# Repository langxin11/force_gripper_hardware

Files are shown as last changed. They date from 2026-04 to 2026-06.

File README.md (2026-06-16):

# Learning Force-Regulated Manipulation with a Low-Cost Tactile-Force-Controlled Gripper



Force Gripper Overview

## Overview

This repository contains the hardware design and assembly guide for our **low-cost tactile-force-controlled gripper**, designed for studying force-regulated manipulation in robot learning. The gripper features:

## Hardware Documentation

This repository provides complete hardware implementation guides:

- **[Bill of Materials (BOM)](BOM.md)** - Complete list of components with prices and suppliers
- **[3D Printing Guide](3D_printing_guide.md)** - Instructions for printing custom parts
- **[Assembly Guide](Assembly_guide.md)** - Step-by-step assembly instructions
- **Tactile sensor** - See [FlexiTac](https://flexitac.github.io)
- **[Code Setup and Usage Guide](code.md)** - Arduino IDE configuration, motor setup, and firmware uploading
- **[Code Architecture Reference](code/README.md)** - Code directory structure, data flow, and parameter quick reference

## Support

Building such a gripper may involve different errors depending on your environment. If you encounter any issues, please feel free to **create an issue** in this repository or send an email to **xuhui@virginia.edu**. I will respond as soon as possible.

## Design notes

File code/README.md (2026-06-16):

# Code — 力控夹爪软件代码

本目录包含下位机固件（OpenRB-150 Arduino 程序）和上位机 ROS 包（Python），实现夹爪的遥操作力控。

---

## 目录结构

```
code/
├── README.md                                   # ← 你正在看的文件
├── openrb150/                                  # 下位机固件（Arduino）
│   ├── control_gripper_width_force/            # 主控：双电机位置/力控
│   ├── teleoperator/                           # 遥操作：读取负载传感器
│   ├── scan_ids/                               # 工具：扫描总线上的舵机 ID
│   ├── update_motor_id/                        # 工具：修改舵机 ID
│   ├── modify_motor_bitrate/                   # 工具：修改舵机波特率
│   └── test_single_motor_control/              # 测试：单电机控制
└── force_control_gripper/                      # 上位机（ROS Python 包）
    ├── force_gripper/                          # 核心模块
    │   ├── gripper/gripper_ros.py              # 夹爪驱动 ROS 节点
    │   ├── teleoperator/teleoperation_ros.py   # 遥操作映射 ROS 节点
    │   ├── tactile/tactile_ros.py              # 触觉传感器 ROS 节点
    │   ├── utils/load_device.py                # 串口设备查找工具
    │   └── config/devices.yaml                 # 设备配置文件
    └── scripts/                                # 独立测试/调试脚本
```

---

## 整体架构

```
 ┌──────────────────────┐      ┌─────────────────────────┐      ┌──────────────────────┐
 │  遥操作手柄 (Arduino) │      │  PC (ROS Noetic)        │      │  OpenRB-150 主控     │
 │                      │      │                         │      │                      │
 │  电机3 & 电机4       │──串口──│  teleoperation_ros.py  │──ROS──│  gripper_ros.py      │──串口──│  control_gripper_    │
 │  (负载传感)          │      │  读取 L3:val,L4:val     │ topic│  构造 JSON 指令      │        │  width_force.ino     │
 │                      │      │  映射为 PWM/Open 指令   │      │  收发 <"cmd",...>    │        │                      │
 └──────────────────────┘      └─────────────────────────┘      └──────────────────────┘
                                                                          │
                               ┌─────────────────────────┐      驱动 PWM  │  电机1 (开合)
                               │  tactile_ros.py         │          ┌─────┴─────┐
                               │  读取左右触觉传感器      │          │  电机2 (开合)
                               │  发布压力图像            │          └───────────┘
                               │  /tactile_left/image_raw │
                               │  /tactile_right/image_raw│
                               └─────────────────────────┘
```

---

## openrb150/ — 下位机固件详解

### `control_gripper_width_force/control_gripper_width_force.ino`（主控程序）

**功能**：驱动夹爪两个 Dynamixel 电机（ID 1 & 2），运行在 PWM 模式：
- 上电自动执行**机械限位标定**（分别找开极限和闭极限）
- **50Hz 主循环**：读取位置 → 计算控制量 → 输出 PWM → 回传状态
- 支持两种控制模式：
  - **位置模式 (MODE_POS)**：上位机下发归一化目标位置 `[0,1]` + 前馈 PWM，板载 P 控制器转换为 PWM
  - **PWM 模式 (MODE_PWM)**：上位机直接下发归一化 PWM `[-1,1]`，直驱电机

**串口**：
| 端口 | 用途 | 波特率 |
|---|---|---|
| `Serial` (USB) | 接收指令 | 1,000,000 |
| `Serial3` (USB2TTL) | 回传状态 | 1,000,000 |

**指令格式**（以 `<"cmd", args>` 通过 USB 串口发送）：
| 指令 | 示例 | 说明 |
|---|---|---|
| `initialization` | `<"initialization">` | 重新执行限位标定 |
| `open` | `<"open">` | 回到全开位置（位置模式） |
| `pos` | `<"pos", 0.5, 0.3>` | 位置模式：目标归一化位置 |
| `motion` | `<"motion", 0.5, 0.1, 0.3, -0.05>` | 位置模式 + 前馈 PWM |
| `pwm` | `<"pwm", 0.2, -0.15>` | PWM 直驱模式：归一化 PWM |

**状态回传格式**（50Hz，Serial3）：
```
<1,pos_norm,tgt_norm,pwm_norm,2,pos_norm,tgt_norm,pwm_norm>
```

---

### `teleoperator/teleoperator.ino`

**功能**：读取遥操作手柄两个电机（ID 3 & 4）的负载值，以 100Hz 频率通过串口输出：
```
L3:50,L4:-20
```
波特率 115200。

---

### 工具固件

| 文件 | 用途 |
|---|---|
| `scan_ids/scan_ids.ino` | 遍历 5 种波特率、0~252 的 ID，ping 发现所有挂载的 Dynamixel 舵机 |
| `update_motor_id/update_motor_id.ino` | 将指定舵机 ID 改为新 ID（需先确保只有目标舵机在线） |
| `modify_motor_bitrate/modify_motor_bitrate.ino` | 将指定舵机波特率从 57600 改为 1000000（1Mbps） |
| `test_single_motor_control/test_single_motor_control.ino` | 单电机基础控制测试 |

---

## force_control_gripper/ — 上位机 ROS 包详解

### `gripper/gripper_ros.py` — 夹爪驱动节点

**节点名**：`gripper_controller`

- 订阅 `/gripper/command`（`std_msgs/String`），接收 JSON 指令
- 通过 `force_gripper.utils.find_port_by_name()` 自动查找串口：`"gripper"` → 指令口，`"gripper_usb2ttl"` → 状态口
- 发送 `<"cmd",...>` 给 Arduino，同时线程读取并解析状态
- 发布 `/gripper/state`（`sensor_msgs/Joy`）：buttons=[ID1, ID2]，axes=[pos, tgt, pwm × 2]

**JSON 指令格式**（通过 `/gripper/command` topic）：
```json
{"node": "gripper", "command": "pos", "value": [0.5, 0.3]}
{"node": "gripper", "command": "pwm", "value": [0.2, -0.1]}
{"node": "gripper", "command": "open"}
{"node": "gripper", "command": "init"}
```

---

### `teleoperator/teleoperation_ros.py` — 遥操作映射节点

**节点名**：`teleop_to_gripper_controller`

- 从 `"teleoperator"` 串口读取 `L3:val,L4:val`
- 归一化后（除以 885），根据负载极性决定夹爪动作：
  - **负载 > 0.02**（外推）→ 发送 `open` 指令（夹爪张开）
  - **负载 < 0**（内收）→ 发送 `pwm` 指令（夹爪闭合），可选平均两电机负载
  - **负载 ~0** → 停止（PWM=[0,0]）
- 发布 JSON 指令到 `/gripper/command`

---

### `tactile/tactile_ros.py` — 触觉传感器节点

**节点名**：`dual_tactile_node`

- 从左右两个触觉传感器串口读取 16×32 压力矩阵
- 背景减除 + 阈值 + 归一化处理
- 发布：
  - `/tactile_left/image_raw`（`sensor_msgs/Image`, 32FC1）
  - `/tactile_right/image_raw`
- 提供服务 `/tactile/reinit`（`std_srvs/Trigger`）用于重新标定基线

---

### `utils/load_device.py` — 串口查找工具

通过 USB 设备描述符关键字自动匹配串口路径，避免每次手动指定 `/dev/ttyUSB*`。

### `config/devices.yaml` — 设备配置

定义各设备的关键字映射。

---

### `scripts/` — 独立脚本

| 脚本 | 用途 |
|---|---|
| `control_gripper_single_file.py` | 最简用：单文件控制夹爪（不依赖 ROS） |
| `keyboard_control_ros.py` | 键盘遥控夹爪 |
| `check_serial_number.py` | 检查并列出系统串口设备 |
| `test_teleoperator_serial.py` | 测试遥操作串口数据读取 |

---

## 快速上手

### 1. 烧录固件
在 Arduino IDE 中分别将以下 `.ino` 文件烧录到两块 OpenRB-150 控制板：
- **主控板**：`openrb150/control_gripper_width_force/`
- **遥操作板**：`openrb150/teleoperator/`

### 2. 安装上位机包
```bash
cd code/force_control_gripper
pip install -e .
```

### 3. 运行
```bash
# 终端 1：夹爪驱动
rosrun force_gripper gripper_ros.py

# 终端 2：遥操作映射
rosrun force_gripper teleoperation_ros.py

# （可选）终端 3：触觉传感器
rosrun force_gripper tactile_ros.py
```

### 4. 调试工具
- 扫描舵机：烧录 `scan_ids.ino`，查看串口监视器
- 修改 ID：烧录 `update_motor_id.ino`
- 修改波特率：烧录 `modify_motor_bitrate.ino`

---

## 关键参数速查

| 参数 | 值 | 位置 |
|---|----|---|
| 主控控制频率 | 50 Hz | `control_gripper_width_force.ino` |
| DXL 舵机波特率 | 1,000,000 bps | 同上 |
| PWM 范围 | [-885, 885] | 同上 |
| 位置控制器 KP | 0.6 | 同上 |
| 遥操作串口波特率 | 115,200 bps | `teleoperator.ino` |
| 遥操作负载归一化因子 | 885.0 | `teleoperation_ros.py` |
| 触觉传感器阵列 | 16 × 32 | `tactile_ros.py` |
| 触觉传感器波特率 | 2,000,000 bps | `tactile_ros.py` |

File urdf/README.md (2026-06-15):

# Force Control Gripper URDF

A two-finger parallel gripper in URDF, with two PyBullet keyboard demos.

This URDF was generated directly by Autodesk Fusion (URDF export); the collision
geometry is the raw exported mesh and has not been optimized. If you have
suggestions for improving it, feel free to reach out: **xuhui@virginia.edu**

## The two demos

- `keyboard_control.py` — both fingers move **together** symmetrically (a single open/close value), like a normal parallel gripper.
- `keyboard_control_independent.py` — each fingertip is controlled **independently** and can travel the full span (one can move all the way across to the other side); they collide with each other instead of passing through.

## Run

```bash
conda install -c conda-forge pybullet   # or: pip install pybullet
python keyboard_control.py
python keyboard_control_independent.py
```

Each script opens a PyBullet GUI; control the gripper with the keyboard (the on-screen prints list the keys, e.g. `O`/`C` to open/close, `Q` to quit).

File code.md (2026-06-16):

- [1. Gripper Setup](#1-gripper-setup)
- [2. Teleoperator Setup](#2-teleoperator-setup)

## Prerequisites

This guide assumes you're using the OpenRB-150 board with Arduino. If you're new to Arduino, we recommend learning the basics first. Configure your Arduino IDE according to the official documentation: [OpenRB-150 Arduino IDE Setup](https://emanual.robotis.com/docs/en/parts/controller/openrb-150/#install-the-arduino-ide).

> 📖 For a technical overview of the code architecture, data flow, and parameter reference, see **[code/README.md](code/README.md)**.

# 1. Gripper Setup

## 1.1 Motor Detection and Setup

Use `code/openrb150/scan_ids` to verify successful connection and detect motors. Motors ship with ID 1 by default. In this example, one motor has been set to ID 2.

Note that 57600 is the baud rate for OpenRB-150 to motor communication, not PC to OpenRB-150. Default is 57600, but we'll upgrade to 2000000 later for better performance.

Expected output when motors are detected:
```
SCAN PROTOCOL 2
SCAN BAUDRATE 57600
ID : 1, Model Number: 1060
ID : 2, Model Number: 1060
SCAN BAUDRATE 115200
SCAN BAUDRATE 1000000
SCAN BAUDRATE 2000000
SCAN BAUDRATE 3000000
Total 2 DYNAMIXEL(s) found!
```

## 1.2 Motor ID Configuration

Motors ship with ID 1 by default. We'll change one to ID 2. Connect only one motor at a time, as the code detects ID 1 and changes it to 2.

Use: `code/openrb150/update_motor_id/update_motor_id.ino`

Set the source and target IDs:
```cpp
const uint8_t source_id = 1;
const uint8_t new_id = 2;
```

Expected output:
```
PROTOCOL 2.0, ID 1: ping succeeded!, Model Number: 1060
ID has been successfully changed to 2
```

## 1.3 Single Motor PWM Test

Load test code to verify PWM control of individual motors.

Use: `code/openrb150/test_single_motor_control/test_single_motor_control.ino`

Configure the target motor ID:
```cpp
const uint8_t DXL_ID = 2;    // Specify Motor ID here
```

After uploading, use Arduino IDE Serial Monitor to test PWM values. Enter values like 200 or -200 (range: -885 to +885) to see forward/reverse rotation.

Serial Test

## 1.4 Main Gripper Control Code

Once testing is successful, upload the main gripper control code.

Use: `code/openrb150/control_gripper_width_force/control_gripper_width_force.ino`

Configure baud rates and other settings at the top of the file. OpenRB-150 to motor communication defaults to 57600. See step 5 for upgrading to 1000000.

After uploading, you'll need a Python script for control and feedback. This guide uses ROS 1. ROS-independent versions may be available later.

## Serial Port Configuration

Serial ports vary by operating system, so we identify them by serial number.

If you purchased a USB2TTL adapter for real-time gripper state feedback, see [Section 1.6: Real-Time Gripper State via USB2TTL](#16-real-time-gripper-state-via-usb2ttl).

1. Run `code/force_control_gripper/scripts/check_serial_number.py` to identify device information
2. Update `code/force_control_gripper/force_gripper/config/devices.yaml` with gripper device info for automatic detection

## Installation

### Package Installation

Navigate to the package directory and install in development mode:

```bash
cd code/force_control_gripper
pip install -e .
```

This will install the `force_gripper` package with its dependencies, allowing you to use the utility functions for serial port detection.

## ROS-Based Control

Run `python code/force_control_gripper/force_gripper/gripper/gripper_ros.py` (requires ROS core to be running).

This establishes communication with the gripper.

## ROS-Independent Interactive Control

For ROS-free operation, use the interactive control script: `code/force_control_gripper/scripts/control_gripper_single_file.py`

Launch the script:
```bash
python code/force_control_gripper/scripts/control_gripper_single_file.py
```

Then enter commands at the `gripper>` prompt:

```
gripper> init          # Initialize
gripper> open          # Fully open
gripper> pos 0.5 0.5   # Set position (0.0-1.0)
gripper> pwm 0.3 -0.3  # PWM control (-1.0 to 1.0)
gripper> state         # Show current status
gripper> help          # Show help
gripper> quit          # Exit
```

If a status serial port (USB2TTL, such as CH340 or CP2102) is available, real-time status will be displayed. Otherwise, status shows as null. If you purchased a USB2TTL adapter, see [Section 1.6: Real-Time Gripper State via USB2TTL](#16-real-time-gripper-state-via-usb2ttl).

## 1.5 Optional: Motor Baud Rate Optimization

Improve communication speed by modifying motor baud rates.

Use: `code/openrb150/modify_motor_bitrate/modify_motor_bitrate.ino`

Configure motor ID and target baud rate at the top of the file. Default is 57600. Testing shows 1000000 provides significant speed improvements.

## 1.6 Real-Time Gripper State via USB2TTL

To read the gripper state in real time, we separate the command serial port from the status serial port.

If you use a USB2TTL adapter such as a CH340 or CP2102, connect it as shown below:

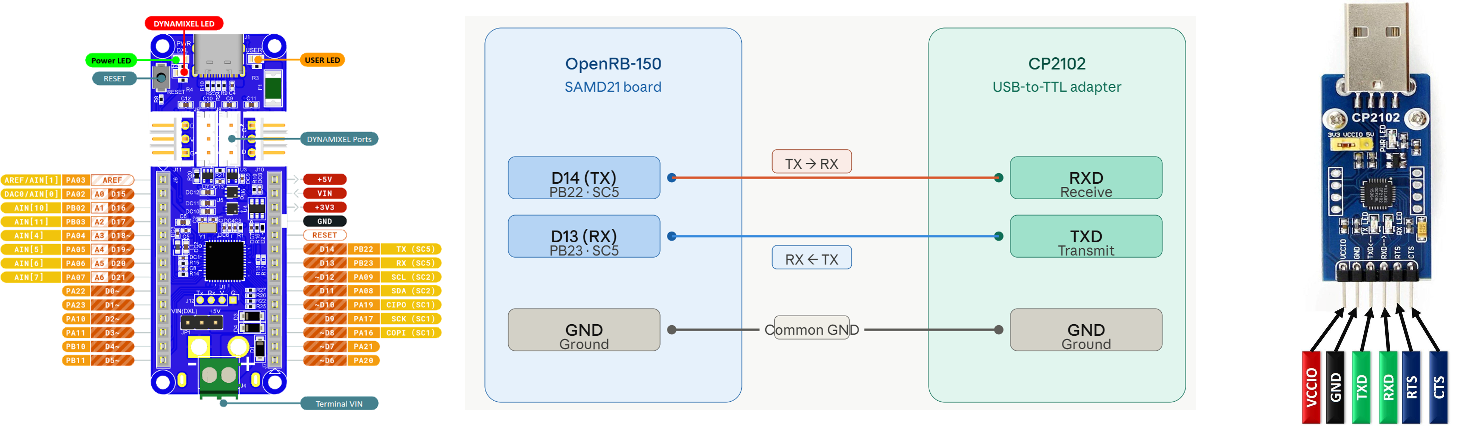
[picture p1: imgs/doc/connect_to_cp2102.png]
USB2TTL wiring for real-time gripper state


Once connected, this serial port will continuously return the gripper state.

## 1.7 Optional: Tactile ROS Publishing

The tactile sensors and the gripper are controlled separately.

If you have built the tactile sensors, you can run `code/force_control_gripper/force_gripper/tactile/tactile_ros.py` to continuously publish tactile information.

```bash
python code/force_control_gripper/force_gripper/tactile/tactile_ros.py
```

This node reads the left and right tactile serial ports independently and continuously publishes tactile data to ROS topics.
# 2. Teleoperator Setup

The teleoperator system uses a separate OpenRB-150 board to read load (force) feedback from two Dynamixel motors (we use IDs 3 and 4). 

## 2.1 Hardware Preparation
1. Connect two Dynamixel motors to the OpenRB-150.
2. Ensure the motors have IDs 3 and 4 (use the `scan_ids` and `update_motor_id` tools if necessary).

## 2.2 Arduino Code Deployment
Use: `code/openrb150/teleoperator/teleoperator.ino`

- **Baud Rate**: The motor communication is set to 57600. The PC serial communication is set to 115200.
- **Output Format**: The board sends data in the format `L3:value,L4:value\n` at approximately 100Hz.

## 2.3 Configuration
Identify the teleoperator's serial number and add it to `code/force_control_gripper/force_gripper/config/devices.yaml`:

```yaml
devices:
  teleoperator:
    serial: "YOUR_SERIAL_NUMBER"
    vid: 33261
    pid: 144
```

## 2.4 Testing the Connection
You can use the dedicated test script to verify that the PC is receiving data correctly:

```bash
python code/force_control_gripper/scripts/test_teleoperator_serial.py
```

The script will automatically find the port, send a wake-up character, and start printing the force/load data from IDs 3 and 4.

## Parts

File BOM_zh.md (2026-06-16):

# force_gripper_hardware

## 物料清单（BOM）

| 名称 | 链接 | 单价 | 所需数量 | 总价 | 备注 |
|---|---|---|---|---|---|
| XL430W250T | [Robotis](https://www.robotis.us/dynamixel-xl430-w250-t/) | $27.50 | 2 | $55.00 | Dynamixel 舵机电机，另需使用随附的 4 颗 M2.5 x 14 螺丝 |
| OpenRB-150 | [Robotis](https://www.robotis.us/openrb-150/) | $28.64 | 1 | $28.64 | 控制板。也可以使用 Dynamixel 官方 U2D2 控制套件，但价格更高 |
| MGN12H Linear Guide Rail 200MM with 2 Blocks | [Amazon](https://www.amazon.com/gp/product/B0C3VGRP6Q/ref=ox_sc_act_title_1?smid=A1YHW98JPGEZ14&th=1) | $24.98 | 1 | $24.98 | 线性导轨和滑块 |
| HTD3M Timing Belt | [Amazon](https://www.amazon.com/gp/product/B09KKXY8YS/ref=ox_sc_act_title_5?smid=A1W08XZBT3V7EI&psc=1) | $11.99 | 1 m | $5.99 | 同步带，需要 1 米 |
| Filament 1kg | [Amazon](https://www.amazon.com/Official-Creality-Precision-Toughness-Moistureproof/dp/B0C8NP63GD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) | $19.99 | 400 g | $7.99 | 每个夹爪约需 400 g，任意品牌均可，PLA、PETG、ABS 理论上都可以使用 |
| TPU 95 Filament 0.75kg | [Amazon](https://www.amazon.com/dp/B09KKZLZVR/ref=twister_B0F3Y1MWFK?_encoding=UTF8&th=1) | $23.99 | 150 g | $4.80 | 约需 150 g，任意品牌均可 |
| Flange Bearing F685-2RS 5x11x5mm | [Amazon](https://www.amazon.com/gp/product/B0D7BYFGVT/ref=ox_sc_act_title_3?smid=A1THAZDOWP300U&th=1) | $13.09 | 2 | $2.62 | 一包 10 个轴承，只需要 2 个 |
| Steel Dowel Pin | [Amazon](https://www.amazon.com/gp/product/B0F5W619BC/ref=ox_sc_act_title_4?smid=A3SSR6IRE5S2JM&psc=1) | $9.99 | 2 | $2.00 | 一包 10 个，只需要 2 个，长度 35 mm |
| AC Adapter 12V 4A | [Amazon](https://www.amazon.com/COOLM-100-240V-Adapter-5-5x2-5mm-5-5x2-1mm/dp/B07H493GHX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) | $11.90 | 1 | $11.90 | 需要 12 V 且大于 3 A，包含接头 |
| Dupont Wire Kit | [Amazon](https://www.amazon.com/Elegoo-EL-CP-004-Multicolored-Breadboard-arduino/dp/B01EV70C78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) | $6.98 | 约 1/3 包 | $2.33 | 用于连接 OpenRB-150 和电机。需要：5 根公对公、3 根母对母 |
| M3 Screw Set | [Amazon](https://www.amazon.com/Kadrick-Assortment-M3x4MM-35MM-Machine-Anti-Rust/dp/B0BRWCFD6Q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) | $19.99 | 约 1/5 包 | $4.00 | 需要：M3 10 mm x 2、M3 35 mm x 6、M3 20 mm x 2、M3 螺母 x 10、M3 8 mm x 8 |
| M6 Screws 12mm with Nuts | [Amazon](https://www.amazon.com/Screws-Assortment-Stainless-Socket-Washers/dp/B0DFWMGFDM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) | $8.99 | 2 | $2.25 | 用于将夹爪安装到 Franka 上（ISO 9409-1-A50）。包装内含 8 颗 M6 x 12 mm 螺丝，只需要 2 颗。也兼容 UR5、xArm 等 |
| M2 Screws 5mm | [Amazon](https://www.amazon.com/Socket-Stainless-Threaded-Furniture-Printing/dp/B0DKY77B3B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) | $6.59 | 8 | $0.88 | 一包 60 颗，需要 8 颗 |
| USB2TTL Serial Module（可选） | [Amazon](https://www.amazon.com/HiLetgo-Module-Microcontroller-Download-Serial/dp/B00LZV1G6K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) | $9.79 | 1 | $1.96 | 用于状态通道的 USB2TTL 适配器，例如 CH340 或 CP2102。对于电机控制和反馈使用独立发送/接收通道的学习场景，这是可选项。一包 5 个，只需要 1 个 |

**总成本：$152.34**

说明：

1. 除电机和 OpenRB-150 之外，其他零件都是标准件，可以购买任意品牌的等效型号。
2. 除 HTD3M 同步带外，我们也测试过 GT2 和 HTD5M。测试发现 GT2 太薄太软，在大力夹持时容易跳齿；HTD5M 则太硬，张紧需要较大力。
3. 使用电机随附的螺丝将电机安装到底座上。
4. 除了需要采购的物料外，还需要螺丝刀套装、剪刀、胶带和 3D 打印机等工具。由于 3D 打印孔位可能不是完全圆形，有时可以用锤子将钢制定位销轻轻敲入。
5. 状态反馈模块可以使用任意 USB2TTL 适配器，例如 CH340 或 CP2102。CH340 模块通常不会暴露序列号，因此多块 CH340 模块同时连接时可能难以区分。如果机器上连接了多个 USB2TTL 适配器，CP2102 或其他带可读序列号的芯片通常更容易管理。

## 遥操作器

如果需要制作一个不带 VR 的遥操作器，只需要：

- 2 x XL430W250T 电机
- 1 x OpenRB-150 控制器
- 1 x 12 V 4 A 交流电源适配器
- 杜邦线

**估算成本：$97.87**

实际使用中我们发现 VR 头显可能比较重。如果感觉太重，建议一只手握持遥操作器，另一只手握持 VR 头显。

## 触觉传感器

触觉传感器制作请参考 [FlexiTac](https://flexitac.github.io/)。

# 参考与致谢

1. [MAGPIE](https://github.com/correlllab/MAGPIE)
2. [UMI](https://umi-gripper.github.io)
3. [FlexiTac](https://flexitac.github.io/)

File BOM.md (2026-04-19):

# force_gripper_hardware

## Bill of Materials (BOM)

| Name | Link | Unit Price | Quantity Needed | Total Price | Notes |
|---|---|---|---|---|---|
| XL430W250T | [Robotis](https://www.robotis.us/dynamixel-xl430-w250-t/) | $27.50 | 2 | $55.00 | Dynamixel servo motor (also need 4 included M2.5×14 screws) |
| OpenRB-150 | [Robotis](https://www.robotis.us/openrb-150/) | $28.64 | 1 | $28.64 | Controller board (can also use Dynamixel's official U2D2 control set, but more expensive) |
| MGN12H Linear Guide Rail 200MM with 2 Blocks | [Amazon](https://www.amazon.com/gp/product/B0C3VGRP6Q/ref=ox_sc_act_title_1?smid=A1YHW98JPGEZ14&th=1) | $24.98 | 1 | $24.98 | Linear rail and carriage blocks |
| HTD3M Timing Belt | [Amazon](https://www.amazon.com/gp/product/B09KKXY8YS/ref=ox_sc_act_title_5?smid=A1W08XZBT3V7EI&psc=1) | $11.99 | 1m | $5.99 | Timing belt (1 meter needed) |
| Filament 1kg | [Amazon](https://www.amazon.com/Official-Creality-Precision-Toughness-Moistureproof/dp/B0C8NP63GD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) | $19.99 | 400g | $7.99 | ~400g needed per gripper, any brand works (PLA, PETG, ABS should all work) |
| TPU 95 Filament 0.75kg | [Amazon](https://www.amazon.com/dp/B09KKZLZVR/ref=twister_B0F3Y1MWFK?_encoding=UTF8&th=1) | $23.99 | 150g | $4.80 | ~150g needed, any brand works |
| Flange Bearing F685-2RS 5x11x5mm | [Amazon](https://www.amazon.com/gp/product/B0D7BYFGVT/ref=ox_sc_act_title_3?smid=A1THAZDOWP300U&th=1) | $13.09 | 2 | $2.62 | Pack of 10 bearings, only 2 needed |
| Steel Dowel Pin | [Amazon](https://www.amazon.com/gp/product/B0F5W619BC/ref=ox_sc_act_title_4?smid=A3SSR6IRE5S2JM&psc=1) | $9.99 | 2 | $2.00 | Pack of 10, only 2 needed (35mm) |
| AC Adapter 12V 4A | [Amazon](https://www.amazon.com/COOLM-100-240V-Adapter-5-5x2-5mm-5-5x2-1mm/dp/B07H493GHX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) | $11.90 | 1 | $11.90 | 12V >3A required, includes connector |
| Dupont Wire Kit | [Amazon](https://www.amazon.com/Elegoo-EL-CP-004-Multicolored-Breadboard-arduino/dp/B01EV70C78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) | $6.98 | ~1/3 | $2.33 | For connecting OpenRB-150 and motors. Need: 5 male-to-male, 3 female-to-female |
| M3 Screw Set | [Amazon](https://www.amazon.com/Kadrick-Assortment-M3x4MM-35MM-Machine-Anti-Rust/dp/B0BRWCFD6Q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) | $19.99 | ~1/5 | $4.00 | Need: M3 10mm ×2, M3 35mm ×6, M3 20mm ×2, M3 nuts ×10, M3 8mm ×8 |
| M6 Screws 12mm with Nuts | [Amazon](https://www.amazon.com/Screws-Assortment-Stainless-Socket-Washers/dp/B0DFWMGFDM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) | $8.99 | 2 | $2.25 | For mounting gripper to Franka (ISO 9409-1-A50). Pack contains 8 M6×12mm screws, only 2 needed. Compatible with UR5, xArm, etc. |
| M2 Screws 5mm | [Amazon](https://www.amazon.com/Socket-Stainless-Threaded-Furniture-Printing/dp/B0DKY77B3B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) | $6.59 | 8 | $0.88 | Pack of 60, 8 needed |
| USB2TTL Serial Module (Optional) | [Amazon](https://www.amazon.com/HiLetgo-Module-Microcontroller-Download-Serial/dp/B00LZV1G6K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) | $9.79 | 1 | $1.96 | USB2TTL adapter for the status channel, such as CH340 or CP2102. Optional for learning scenarios with separate send/receive channels for motor control and feedback. Pack of 5, 1 needed. |

**Total Cost: $152.34**

Notes:
1. Except for the motors and OpenRB-150, all other components are standard parts. You can purchase equivalent models from any brand.
2. Besides HTD3M timing belt, we also tested GT2 and HTD5M. We found that GT2 is too thin and soft, prone to tooth skipping under high force, while HTD5M is too stiff and requires significant force to tension.
3. Use the included screws from the motors to mount them to the base.
4. Besides the items to purchase, you will need some tools including a screwdriver set, scissors, tape, and a 3D printer. Since 3D printed holes may not be perfectly round, you can sometimes use a hammer to tap in the Steel Dowel Pins.
5. The status feedback module can be any USB2TTL adapter, such as CH340 or CP2102. CH340 modules often do not expose a serial number, so different CH340 modules may be hard to distinguish. If your machine connects to multiple USB2TTL adapters, CP2102 or another chip with a readable serial number is usually easier to manage.
## Teleoperator

If you need to build a teleoperator (without VR), you only need:

- 2 × XL430W250T motors
- 1 × OpenRB-150 controller
- 1 × AC Adapter 12V 4A
- Dupont wires

**Approximate cost: $97.87**

During actual use, we found that VR headsets can be quite heavy, so if it feels too heavy, we recommend holding the teleoperator in one hand and the VR headset in the other hand.

## Tactile Sensor
For tactile sensor fabrication, please refer to [FlexiTac](https://flexitac.github.io/).

# References and Acknowledgments
1. [MAGPIE](https://github.com/correlllab/MAGPIE)
2. [UMI](https://umi-gripper.github.io)
3. [FlexiTac](https://flexitac.github.io/)

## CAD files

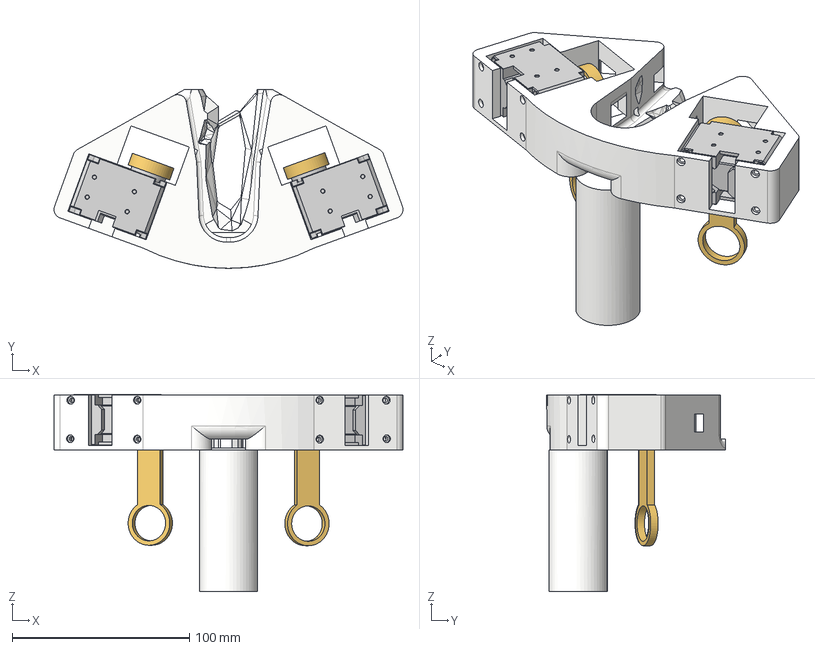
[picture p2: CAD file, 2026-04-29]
cad/teleoperator.step
197.0 x 100.8 x 111.2 mm
DC11_A01_DUMMY
human_figure x 2
DC11_A01_DUMMY_1
DX124_SCREW-COVER_1
B3B-EH_1 x 2
DC11_A01_CASE_CVR_DUMMY_1
DC11_A01_IDLER_DUMMY_1
DC11_A01_IDLER_CAP_DUMMY_1
DC11_A01_IDLER_SCREW_1
FHS_M2_5X10_1 x 8
DC11_A01_SPACER_DUMMY_1 x 8

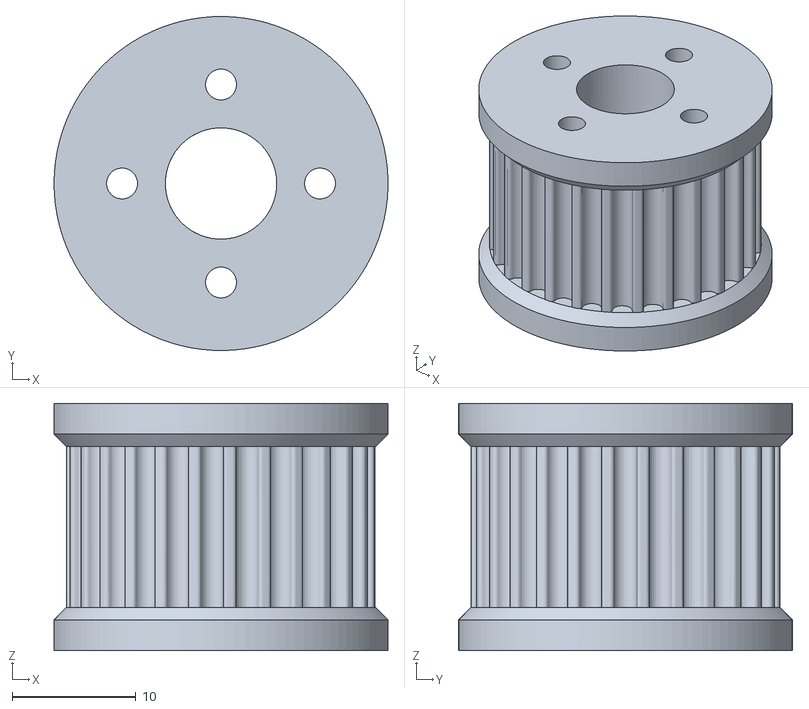
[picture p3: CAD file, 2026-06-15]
print_parts/driving_pulley.stl
27.0 x 27.0 x 20.0

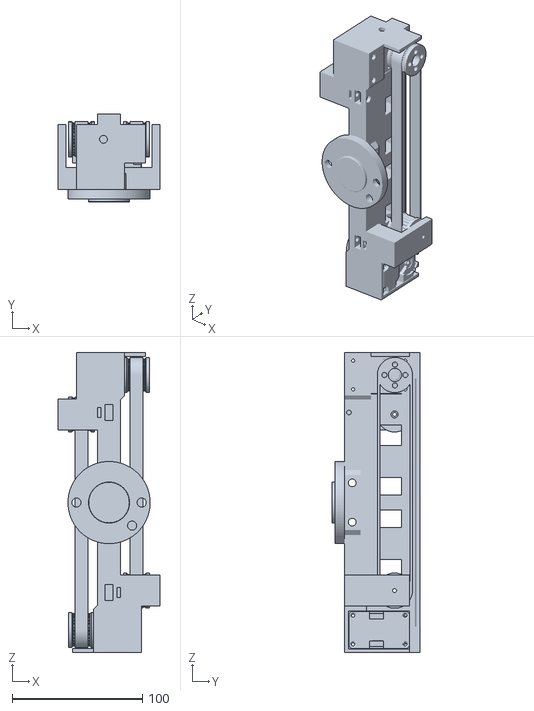
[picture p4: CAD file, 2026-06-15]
urdf/meshes/base-1.stl
78.0 x 67.5 x 230.0

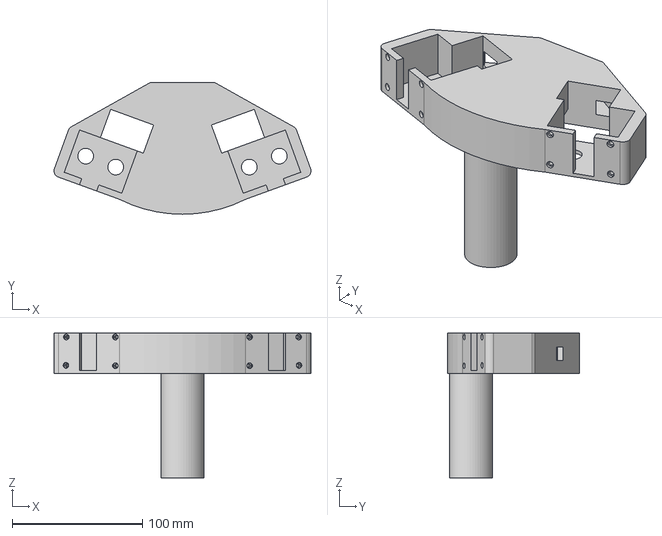
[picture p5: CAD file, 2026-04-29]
cad/teleoperator_solid.step
197.0 x 100.8 x 111.0 mm

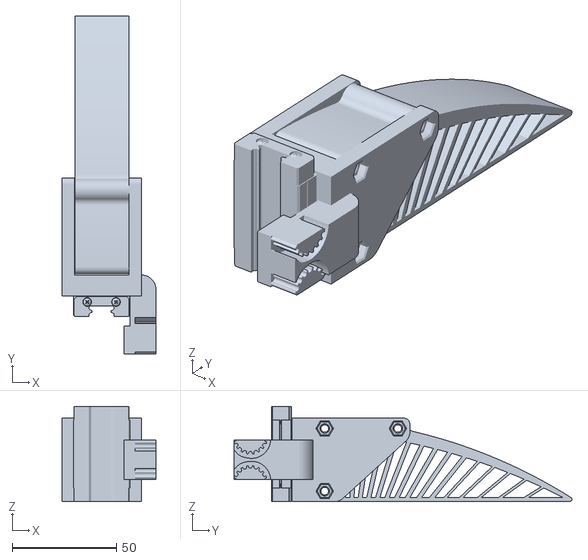
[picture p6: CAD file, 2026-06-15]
urdf/meshes/right_figure.stl
45.0 x 161.9 x 45.6

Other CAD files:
urdf/meshes/left_figure.stl

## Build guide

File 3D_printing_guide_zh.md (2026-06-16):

# 3D 打印指南

3D 打印机没有品牌限制，只要能打印 TPU/PLA/PETG 即可。大多数主流打印机都可以使用。作者本人使用的是 BambuLab P1S 和 Creality Ender V2。

只有指尖部分需要使用 TPU 打印。其他所有零件都可以使用 PLA、PETG、ABS 等刚性材料。

需要打印的零件：

1. **框架** - [holder_base.stl](./print_parts/holder_base.stl)
   - 推荐填充率大于 45%，以保证强度。使用 100% 填充也可以。
   - 框架

2. **指尖固定座** x 2 - [gripper_figure_tip_holder.stl](./print_parts/gripper_figure_tip_holder.stl)
   - 推荐填充率 100%。
   - 指尖固定座

3. **从动同步轮** x 2 - [idler_pulley.stl](./print_parts/idler_pulley.stl)
   - 推荐填充率 100%。
   - 从动同步轮

4. **主动同步轮** x 2 - [driving_pulley.stl](./print_parts/driving_pulley.stl)
   - 推荐填充率 100%。
   - 主动同步轮

5. **UMI 指尖** x 2 - [UMI_figure_tip.stl](./print_parts/UMI_figure_tip.stl)
   - 使用 TPU 打印，填充率 100%。建议一次只打印一个，不要两个一起打印，因为 TPU 容易拉丝。
   - UMI 指尖

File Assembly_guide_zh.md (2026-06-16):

# 装配指南

装配过程比较直接，大约需要 15 分钟。所需采购零件请参考 [BOM_zh.md](BOM_zh.md)，3D 打印零件请参考 [3D_printing_guide_zh.md](3D_printing_guide_zh.md)。此外还需要胶带、螺丝刀套装和剪刀等工具。

## 1. 安装从动同步轮

从动同步轮安装

- 按照 1️⃣：从左右两侧插入两个法兰轴承。
- 按照 2️⃣：将同步轮本体放入对应位置，此时先不要插入销钉。
- 按照 3️⃣：将销钉插入孔中。由于 3D 打印公差影响，销钉可能无法顺畅滑入。如有需要，可以用锤子轻轻敲入。
- 在侧面使用一颗 20 mm M3 螺丝和螺母固定销钉，防止松脱。

## 2. 安装线性导轨

线性导轨安装

在中间安装两颗 M3 x 10 mm 螺丝来固定线性导轨，并从下方用螺母锁紧。

## 3. 安装电机和主动同步轮

电机和主动同步轮安装

- 按照 1️⃣：拆下电机底部原有的两颗螺丝。
- 按照 2️⃣：将电机放入框架，并安装电机随附的两颗螺丝。
- 按照 3️⃣：使用四颗 M2 螺丝将主动同步轮固定到电机上。

## 4. 安装手指和同步带

手指和同步带安装

- 按照 1️⃣：使用 M3 螺丝将指尖固定座安装到滑块上。
- 按照 2️⃣：安装指尖。
- 按照 3️⃣：将同步带固定在固定座中。确保同步带张紧合适，避免跳齿。

## 5. 接线和最终装配

使用随附线缆连接两个电机和 OpenRB-150。将交流电源适配器连接到 OpenRB-150 的一端，注意确认极性正确。另一端使用 USB-C 线缆与主机电脑通信。

OpenRB-150 接线

随附线缆相对较短，因此可能需要使用杜邦线延长。连接处可用胶带固定。OpenRB-150 可以通过较长线缆连接到电机，这样就可以将控制板安装在机器人后方，而不是直接安装在夹爪上。

为此我设计了一个安装盒，使用 M2 自攻螺丝固定。文件见：

- [openrb150_box_base.stl](./print_parts/openrb150_box_base.stl)
- [openrb150_box_cover.stl](./print_parts/openrb150_box_cover.stl)

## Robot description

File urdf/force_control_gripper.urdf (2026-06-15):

<?xml version='1.0' encoding='utf-8'?>
<robot name="force_control_gripper">
    <link name="left_figure">
        <inertial>
            <origin xyz="0.0039140878713019465 0.0363213180478208 -0.019212149166772524" rpy="0.0 -0.0 0.0" />
            <mass value="0.7290858212317849" />
            <inertia ixx="0.0009567320931237102" iyy="0.00018598568132813936" izz="0.0009503563127682703" ixy="-4.319953187031681e-05" iyz="-6.712899236421582e-05" ixz="-1.8346003333227254e-07" />
        </inertial>
        <visual name="left_figure_visual">
            <origin xyz="0.0054782322593601405 -0.002538307703411997 0.054754926046441506" rpy="-3.141592653589793 3.570089879990766e-13 -3.141592653589793" />
            <geometry>
                <mesh filename="meshes/left_figure.stl" scale="0.001 0.001 0.001" />
            </geometry>
        </visual>
        <collision name="left_figure_collision">
            <origin xyz="0.0054782322593601405 -0.002538307703411997 0.054754926046441506" rpy="-3.141592653589793 3.570089879990766e-13 -3.141592653589793" />
            <geometry>
                <mesh filename="meshes/left_figure.stl" scale="0.001 0.001 0.001" />
            </geometry>
        </collision>
    </link>
    <link name="right_figure">
        <inertial>
            <origin xyz="0.007085909275558089 -0.036321318047820905 0.030787850065817714" rpy="0.0 -0.0 0.0" />
            <mass value="0.729085821231785" />
            <inertia ixx="0.0009567320931237119" iyy="0.0001859856813281411" izz="0.0009503563127682708" ixy="-4.319953187031697e-05" iyz="6.712899236421604e-05" ixz="1.834600333322099e-07" />
        </inertial>
        <visual name="right_figure_visual">
            <origin xyz="0.005521764887499895 0.002538307703411878 0.10475492527903174" rpy="-3.141592653589793 3.5688652331916185e-13 0.0" />
            <geometry>
                <mesh filename="meshes/right_figure.stl" scale="0.001 0.001 0.001" />
            </geometry>
        </visual>
        <collision name="right_figure_collision">
            <origin xyz="0.005521764887499895 0.002538307703411878 0.10475492527903174" rpy="-3.141592653589793 3.5688652331916185e-13 0.0" />
            <geometry>
                <mesh filename="meshes/right_figure.stl" scale="0.001 0.001 0.001" />
            </geometry>
        </collision>
    </link>
    <link name="base-1">
        <inertial>
            <origin xyz="6.886875168914372e-06 -0.03027526112285501 0.00011938041814217152" rpy="0.0 0.0 0.0" />
            <mass value="2.860956390976862" />
            <inertia ixx="0.015979939915842623" iyy="0.015695110232053375" izz="0.001461791518230924" ixy="-1.2192499532982057e-06" iyz="-2.9345391647553618e-06" ixz="0.0008557882295470238" />
        </inertial>
        <visual name="base-1_visual">
            <origin xyz="0.0 0.0 0.0" rpy="0.0 0.0 0.0" />
            <geometry>
                <mesh filename="meshes/base-1.stl" scale="0.001 0.001 0.001" />
            </geometry>
        </visual>
        <collision name="base-1_collision">
            <origin xyz="0.0 0.0 0.0" rpy="0.0 0.0 0.0" />
            <geometry>
                <mesh filename="meshes/base-1.stl" scale="0.001 0.001 0.001" />
            </geometry>
        </collision>
    </link>
    <joint name="base-1_Slider-15" type="prismatic">
        <origin xyz="-0.00548381 0.0025 -0.05" rpy="0.0 -0.0 0.0" />
        <parent link="base-1" />
        <child link="left_figure" />
        <axis xyz="0.0 0.0 1.0" />
        <limit lower="0.0" upper="0.0992" effort="1000000" velocity="1000000" />
    </joint>
    <joint name="base-1_Slider-16" type="prismatic">
        <origin xyz="-0.00548381 0.0025 0.1" rpy="3.141592653589793 -0.0 0.0" />
        <parent link="base-1" />
        <child link="right_figure" />
        <axis xyz="0.0 0.0 1.0" />
        <limit lower="0.0" upper="0.0992" effort="1000000" velocity="1000000" />
    </joint>
</robot>

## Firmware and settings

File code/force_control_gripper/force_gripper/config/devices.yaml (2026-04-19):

devices:
  right:               # Right tactile sensor serial device
    vid: 1027          # 0x0403 (FTDI)
    pid: 24577         # 0x6001
    serial: "B0012Y6T"
    manufacturer: "FTDI"

  left:                # Left tactile sensor serial device
    vid: 1027
    pid: 24577
    serial: "B0012Q7H"
    manufacturer: "FTDI"

  gripper:
    vid: 12125         # Microsoft USB-Serial bridge
    pid: 8706
    serial: "9520190A50304A46462E3120FF0A1215"
    manufacturer: "Microsoft"

  gripper_usb2ttl:       # USB2TTL status adapter, e.g. CH340 or CP2102
    vid: 6790
    pid: 29987
    serial: null
    manufacturer: null

  teleoperator:
    vid: 12125         # Microsoft USB-Serial bridge
    pid: 8706
    serial: "B493AA7D50304A46462E3120FF0D152C"
    manufacturer: "Microsoft"

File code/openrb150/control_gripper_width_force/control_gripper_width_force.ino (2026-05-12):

#include <Dynamixel2Arduino.h>
using namespace ControlTableItem;

// ======================= Ports/Baud Rates =======================
#define DXL_SERIAL   Serial1              // DYNAMIXEL bus fixed to Serial1
const int      DXL_DIR_PIN   = -1;
const uint32_t DXL_BAUD      = 1000000;   // If you changed to 1Mbps, set to 1000000

#define CMD_PORT     Serial               // Command input port: default USB.
#define STAT_PORT    Serial3              // Status output port: default USB2TTL adapter (e.g. CH340 or CP2102).
const uint32_t CMD_BAUD   = 1000000;
const uint32_t STAT_BAUD  = 1000000;

// ======================= Motors & Control ========================
const uint8_t  DXL_ID_1    = 1;
const uint8_t  DXL_ID_2    = 2;
const int16_t  PWM_MIN     = -885;
const int16_t  PWM_MAX     =  885;

const float    KP          = 0.6f;        // Position error->PWM proportional coefficient (tunable)
const int32_t  OFFSET_COUNTS = 20;        // Initial position offset relative to open (counts)

// Initialization stability parameters (adjustable based on mechanics)
const int16_t  INIT_PWM_OPEN   =  200;    // PWM used when finding open-side limit (your definition: positive = open)
const int16_t  INIT_PWM_CLOSE  = -200;    // PWM used when finding close-side limit (your definition: negative = close)
const uint16_t STABLE_WINDOW   = 8;       // Consecutive N sampling windows
const int32_t  STABLE_EPS      = 2;       // Stability threshold (counts)
const uint32_t INIT_TIMEOUT_MS = 10000;   // Single segment search timeout

// 50Hz main loop
const uint32_t LOOP_HZ    = 50;
const uint32_t LOOP_DT_MS = 1000 / LOOP_HZ;

// ---- RAW addresses for X/XL series ----
const uint16_t ADDR_PRESENT_POSITION  = 132;
const uint16_t LEN_PRESENT_POSITION   = 4;

const int32_t  RETURN_OPEN_EPS      = 5;     // Tolerance for returning to open_limit (counts)
const uint32_t RETURN_OPEN_TIMEOUT  = 10000; // Timeout for returning to open_limit (ms)

// Write method switch: 1=bulkWrite; 0=twice writeControlTableItem (default 0, keeps your existing logic)
#define USE_BULK 0
// Read method switch: 1=syncRead; 0=twice readControlTableItem (comparison/fallback)
#define USE_SYNC_READ 1

// ======================= Control Modes ========================
// MODE_POS: Host sends "position target(0..1) + feedforward PWM", board uses KP to convert error to PWM
// MODE_PWM: Host sends PWM target directly, board forwards as-is
enum ControlMode : uint8_t { MODE_POS = 0, MODE_PWM = 1 };
volatile ControlMode g_mode = MODE_POS;  // Default position mode

// ======================= Global Objects/Cache ========================
Dynamixel2Arduino dxl(DXL_SERIAL, DXL_DIR_PIN);

// syncRead structure (following new interface)
ParamForSyncReadInst_t    sync_read_param;
RecvInfoFromStatusInst_t  sync_read_result;

// Optional: bulkWrite structure (only when USE_BULK=1)
#if USE_BULK
const uint16_t ADDR_GOAL_PWM = 100;   // X/XL series Goal PWM address
const uint16_t LEN_GOAL_PWM  = 2;
ParamForBulkWriteInst_t   bulk_write_param;
#endif

// Position cache
volatile int32_t g_pos1 = 0, g_pos2 = 0;

// Limits and mapping
int32_t open_limit[2]  = {0, 0};
int32_t close_limit[2] = {4095, 4095};
bool    limits_valid   = false;

// Targets (position mode: 0~1) and feedforward PWM (used in position mode)
float   goal_norm_1 = 0.0f;
float   goal_norm_2 = 0.0f;
int16_t feed_pwm_1  = 0;
int16_t feed_pwm_2  = 0;

// Targets (PWM mode: direct output)
int16_t pwm_goal_1  = 0;
int16_t pwm_goal_2  = 0;

// ======================= Utility Functions ========================
static inline int16_t clamp_pwm(long v){
  if (v < PWM_MIN) return PWM_MIN;
  if (v > PWM_MAX) return PWM_MAX;
  return (int16_t)v;
}
static inline int32_t lerp_counts(int32_t a, int32_t b, float t){
  if (t < 0.f) t = 0.f; if (t > 1.f) t = 1.f; return a + (int32_t)((b - a) * t);
}

// ======================= DXL Initialization =========================
void setup_motors_to_pwm_mode(){
  const uint8_t ids[2] = {DXL_ID_1, DXL_ID_2};
  for (int i = 0; i < 2; ++i){
    uint8_t id = ids[i];
    if (!dxl.ping(id)){
      CMD_PORT.print("[ERR] ping failed id="); CMD_PORT.println(id);
      while (1) { delay(1000); }
    }
    dxl.torqueOff(id);
    dxl.writeControlTableItem((uint8_t)OPERATING_MODE, id, (int32_t)16, (uint32_t)10); // 16 = PWM(mode)
    
    // [Critical modification]
    // 1 = Reply only to READ instructions
    // 2 = Reply to both READ and WRITE instructions
    // Your writeControlTableItem function waits for WRITE instruction response packets,
    // so this must be set to 2, otherwise writeControlTableItem will timeout and return false.
    dxl.writeControlTableItem((uint8_t)STATUS_RETURN_LEVEL, id, (int32_t)2, (uint32_t)10);

    dxl.writeControlTableItem((uint8_t)RETURN_DELAY_TIME,   id, (int32_t)0, (uint32_t)10);
    dxl.torqueOn(id);
  }
}

// ======================= Group Read Configuration =========================
void setup_sync_read(){
  sync_read_param.addr      = ADDR_PRESENT_POSITION;
  sync_read_param.length    = LEN_PRESENT_POSITION;
  sync_read_param.xel[0].id = DXL_ID_1;
  sync_read_param.xel[1].id = DXL_ID_2;
  sync_read_param.id_count  = 2;
}

#if USE_BULK
// ======================= Group Write Configuration (only when USE_BULK=1) =========================
void setup_bulk_write(){
  bulk_write_param.id_count      = 2;
  bulk_write_param.xel[0].id     = DXL_ID_1;
  bulk_write_param.xel[0].addr   = ADDR_GOAL_PWM;
  bulk_write_param.xel[0].length = LEN_GOAL_PWM;
  bulk_write_param.xel[1].id     = DXL_ID_2;
  bulk_write_param.xel[1].addr   = ADDR_GOAL_PWM;
  bulk_write_param.xel[1].length = LEN_GOAL_PWM;
}
#endif

// ======================= Read Position =============================
bool read_positions_dual(){
#if USE_SYNC_READ
  if (!dxl.syncRead(sync_read_param, sync_read_result)) { CMD_PORT.println("[syncRead][FAIL]"); return false; }
  int32_t t1 = 0, t2 = 0; bool got1 = false, got2 = false;
  for (uint8_t i = 0; i < sync_read_result.id_count; ++i) {
    const uint8_t id = sync_read_result.xel[i].id;
    const uint16_t len = sync_read_result.xel[i].length;
    const uint8_t* d = sync_read_result.xel[i].data;
    if (len >= 4) {
      int32_t v =  (int32_t)((uint32_t)d[0] | ((uint32_t)d[1] << 8) | ((uint32_t)d[2] << 16) | ((uint32_t)d[3] << 24));
      if (id == DXL_ID_1) { t1 = v; got1 = true; }
      if (id == DXL_ID_2) { t2 = v; got2 = true; }
    }
  }
  if (!got1 || !got2) {
    CMD_PORT.print("[syncRead][PARTIAL] got1="); CMD_PORT.print(got1);
    CMD_PORT.print(" got2="); CMD_PORT.println(got2);
    if (got1) g_pos1 = t1; if (got2) g_pos2 = t2; return false;
  }
  g_pos1 = t1; g_pos2 = t2; return true;
#else
  int32_t t1 = dxl.readControlTableItem((uint8_t)PRESENT_POSITION, (uint8_t)DXL_ID_1);
  int32_t t2 = dxl.readControlTableItem((uint8_t)PRESENT_POSITION, (uint8_t)DXL_ID_2);
  bool ok1 = (t1 != -1), ok2 = (t2 != -1);
  if (!ok1 || !ok2) { CMD_PORT.print("[read][FAIL] ok1="); CMD_PORT.print(ok1); CMD_PORT.print(" ok2="); CMD_PORT.println(ok2); }
  g_pos1 = t1; g_pos2 = t2; return ok1 && ok2;
#endif
}

// ======================= Write PWM (Dual Channel, Single Write Version) =====================
bool write_pwm_dual(int16_t pwm1, int16_t pwm2){
  pwm1 = clamp_pwm(pwm1);
  pwm2 = clamp_pwm(pwm2);
#if USE_BULK
  // ---- bulkWrite path (only enabled when USE_BULK=1) ----
  bulk_write_param.xel[0].data[0] = (uint8_t)(pwm1 & 0xFF);
  bulk_write_param.xel[0].data[1] = (uint8_t)((pwm1 >> 8) & 0xFF);
  bulk_write_param.xel[1].data[0] = (uint8_t)(pwm2 & 0xFF);
  bulk_write_param.xel[1].data[1] = (uint8_t)((pwm2 >> 8) & 0xFF);
  bool ok = dxl.bulkWrite(bulk_write_param);
  if (!ok){
    CMD_PORT.print("[bulkWrite][FAIL] pwm=("); CMD_PORT.print(pwm1); CMD_PORT.print(","); CMD_PORT.print(pwm2); CMD_PORT.println(")");
    return false;
  }
  return true;
#else
  // ---- Default path: two single writes (keep your existing logic unchanged) ----
  // [Modified] Increased timeout from 5ms to 10ms, 5ms may be too short for write operation + waiting for response packet
  bool ok1 = dxl.writeControlTableItem((uint8_t)GOAL_PWM, (uint8_t)DXL_ID_1, (int32_t)pwm1, (uint32_t)10);
  bool ok2 = dxl.writeControlTableItem((uint8_t)GOAL_PWM, (uint8_t)DXL_ID_2, (int32_t)pwm2, (uint32_t)10);
  if(!(ok1 && ok2)){
    CMD_PORT.print("[write][FAIL] pwm=("); CMD_PORT.print(pwm1); CMD_PORT.print(","); CMD_PORT.print(pwm2); CMD_PORT.println(")");
    return false;
  }
  return true;
#endif
}

// ======================= Stability Judgment Tools ==========================
bool is_stable(const int32_t* hist, uint16_t n, int32_t eps){
  if (n < 2) return false; int32_t minv = hist[0], maxv = hist[0];
  for (uint16_t i = 1; i < n; ++i){ if (hist[i] < minv) minv = hist[i]; if (hist[i] > maxv) maxv = hist[i]; }
  return (maxv - minv) <= eps;
}

// ======================= Initialization Process ========================
void run_initialization(){
  CMD_PORT.println("[init] start");
  write_pwm_dual(0, 0); delay(50);

  // Step1: Find open side
  {
    int32_t hist1[STABLE_WINDOW] = {0};
    int32_t hist2[STABLE_WINDOW] = {0};
    uint16_t idx = 0; uint32_t t0 = millis();
    while (true){
      CMD_PORT.println("[init] searching open-limit...");
      write_pwm_dual(INIT_PWM_OPEN, INIT_PWM_OPEN);
      delay(50);
      (void)read_positions_dual();
      hist1[idx % STABLE_WINDOW] = g_pos1; hist2[idx % STABLE_WINDOW] = g_pos2; idx++;
      bool s1 = (idx >= STABLE_WINDOW) && is_stable(hist1, STABLE_WINDOW, STABLE_EPS);
      bool s2 = (idx >= STABLE_WINDOW) && is_stable(hist2, STABLE_WINDOW, STABLE_EPS);
      if (s1 && s2) break; if (millis() - t0 > INIT_TIMEOUT_MS){ CMD_PORT.println("[init] open-limit timeout"); break; }
    }
    write_pwm_dual(0, 0); delay(100); (void)read_positions_dual();
    open_limit[0] = g_pos1; open_limit[1] = g_pos2;
    CMD_PORT.print("[init] open_limit = "); CMD_PORT.print(open_limit[0]); CMD_PORT.print(", "); CMD_PORT.println(open_limit[1]);
  }

  // Step2a: M1 -> close side, then return to open side limit, avoid pressing against M2
  {
    int32_t hist[STABLE_WINDOW] = {0}; uint16_t idx = 0; uint32_t t0 = millis();
    CMD_PORT.println("[init] step2a: M1 -> close-limit");
    while (true){
      if(!write_pwm_dual(INIT_PWM_CLOSE, 0)) { CMD_PORT.println("[init] step2a: write fail"); return; }
      delay(LOOP_DT_MS);
      if(!read_positions_dual()){ CMD_PORT.println("[init] step2a: read fail"); return; }
      hist[idx % STABLE_WINDOW] = g_pos1; idx++;
      if ((idx >= STABLE_WINDOW) && is_stable(hist, STABLE_WINDOW, STABLE_EPS)) break;
      if (millis() - t0 > INIT_TIMEOUT_MS){ CMD_PORT.println("[init] step2a: timeout"); break; }
    }
    write_pwm_dual(0, 0); delay(100); (void)read_positions_dual();
    close_limit[0] = g_pos1; CMD_PORT.print("[init] close_limit.M1="); CMD_PORT.println(close_limit[0]);

    // Return to open side limit
    CMD_PORT.print("[init] step2a-return: M1 -> open_limit[0] = "); CMD_PORT.println(open_limit[0]);
    uint32_t t1 = millis();
    while (true){
      if(!write_pwm_dual(INIT_PWM_OPEN, 0)) { CMD_PORT.println("[init] step2a-return: write fail"); return; }
      delay(LOOP_DT_MS);
      if(!read_positions_dual()){ CMD_PORT.println("[init] step2a-return: read fail"); return; }
      if (abs(g_pos1 - open_limit[0]) <= RETURN_OPEN_EPS) break;
      if (millis() - t1 > RETURN_OPEN_TIMEOUT){ CMD_PORT.println("[init] step2a-return: timeout"); break; }
    }
    write_pwm_dual(0, 0); delay(50);
  }

  // Step2b: M2 -> close side
  {
    int32_t hist[STABLE_WINDOW] = {0}; uint16_t idx = 0; uint32_t t0 = millis();
    CMD_PORT.println("[init] step2b: M2 -> close-limit");
    while (true){
      if(!write_pwm_dual(0, INIT_PWM_CLOSE)) { CMD_PORT.println("[init] step2b: write fail"); return; }
      delay(LOOP_DT_MS);
      if(!read_positions_dual()){ CMD_PORT.println("[init] step2b: read fail"); return; }
      hist[idx % STABLE_WINDOW] = g_pos2; idx++;
      if ((idx >= STABLE_WINDOW) && is_stable(hist, STABLE_WINDOW, STABLE_EPS)) break;
      if (millis() - t0 > INIT_TIMEOUT_MS){ CMD_PORT.println("[init] step2b: timeout"); break; }
    }
    write_pwm_dual(0, 0); delay(100); (void)read_positions_dual();
    close_limit[1] = g_pos2; CMD_PORT.print("[init] close_limit.M2="); CMD_PORT.println(close_limit[1]);
  }

  limits_valid = true;

  // Return to open + offset initial position (P control for several steps)
  int32_t init1 = open_limit[0] + OFFSET_COUNTS;
  int32_t init2 = open_limit[1] + OFFSET_COUNTS;
  for (int i = 0; i < 60; ++i){
    (void)read_positions_dual();
    int16_t u1 = clamp_pwm((int32_t)(KP * (init1 - g_pos1)));
    int16_t u2 = clamp_pwm((int32_t)(KP * (init2 - g_pos2)));
    write_pwm_dual(u1, u2);
    delay(LOOP_DT_MS);
  }
  write_pwm_dual(0, 0);
  CMD_PORT.println("[init] done");
}

// ======================= Command Parsing ==========================
void handle_command_line(String &line){
  line.trim(); if (line.length() == 0) return;
  int lt = line.indexOf('<'); int gt = line.lastIndexOf('>'); if (lt == -1 || gt == -1 || gt <= lt) return; 
  String inside = line.substring(lt + 1, gt); inside.trim();

  int comma = inside.indexOf(',');
  String cmd = (comma == -1) ? inside : inside.substring(0, comma); cmd.trim();
  if (cmd.length() >= 2 && cmd.charAt(0) == '"' && cmd.charAt(cmd.length()-1) == '"') cmd = cmd.substring(1, cmd.length()-1);
  CMD_PORT.println("[cmd] received: " + line);

  if (cmd.equalsIgnoreCase("initialization")){
    CMD_PORT.println("[cmd] run init");
    run_initialization();
    return;
  }
  else if (cmd.equalsIgnoreCase("open")){
    // Set target to 0 (open end), and switch back to position mode
    g_mode = MODE_POS;
    goal_norm_1 = 0.f; goal_norm_2 = 0.f; feed_pwm_1 = 0; feed_pwm_2 = 0;
    CMD_PORT.println("[cmd] open -> MODE_POS");
    return;
  }
  else if (cmd.equalsIgnoreCase("pos")){
    // [New] Simplified position target: <"pos", m1_goal_pos_norm, m2_goal_pos_norm>
    String rest = (comma == -1) ? "" : inside.substring(comma + 1); rest.trim();
    int c1 = rest.indexOf(','); if (c1 == -1) return; String s1 = rest.substring(0, c1); String s2 = rest.substring(c1+1);
    s1.trim(); s2.trim();
    float g1 = s1.toFloat(); float g2 = s2.toFloat();
    
    // Set targets and zero out feedforward
    goal_norm_1 = g1; goal_norm_2 = g2; 
    feed_pwm_1 = 0; feed_pwm_2 = 0;
    
    // Switch to position mode
    g_mode = MODE_POS;
    
    CMD_PORT.print("[cmd] MODE_POS (simple) g=("); CMD_PORT.print(goal_norm_1); CMD_PORT.print(", "); CMD_PORT.print(goal_norm_2); CMD_PORT.println(")");
    return;
  }
  else if (cmd.equalsIgnoreCase("motion")){
    // [Retained] Full position target: <"motion", m1_goal_pos_norm, m1_feed_pwm_norm, m2_goal_pos_norm, m2_feed_pwm_norm>
    String rest = (comma == -1) ? "" : inside.substring(comma + 1); rest.trim();
    int c1 = rest.indexOf(','); if (c1 == -1) return; String s1 = rest.substring(0, c1); rest = rest.substring(c1+1);
    int c2 = rest.indexOf(','); if (c2 == -1) return; String s2 = rest.substring(0, c2); rest = rest.substring(c2+1);
    int c3 = rest.indexOf(','); if (c3 == -1) return; String s3 = rest.substring(0, c3); String s4 = rest.substring(c3+1);
    s1.trim(); s2.trim(); s3.trim(); s4.trim();
    
    // [Modified] Parse normalized position(0..1) and normalized feedforward PWM(-1..1)
    float g1 = s1.toFloat(); 
    float ff_norm_1 = s2.toFloat(); // Previously s2.toInt()
    float g2 = s3.toFloat();
    float ff_norm_2 = s4.toFloat(); // Previously s4.toInt()
    
    // Set targets and feedforward
    goal_norm_1 = g1;
    goal_norm_2 = g2;
    // [Modified] Denormalize PWM
    feed_pwm_1 = clamp_pwm((long)(ff_norm_1 * PWM_MAX));
    feed_pwm_2 = clamp_pwm((long)(ff_norm_2 * PWM_MAX));
    
    // Switch to position mode
    g_mode = MODE_POS;
    CMD_PORT.print("[cmd] MODE_POS (full) g=("); CMD_PORT.print(goal_norm_1); CMD_PORT.print(", "); CMD_PORT.print(goal_norm_2);
    // [Modified] Print normalized feedforward
    CMD_PORT.print(") ff_norm=("); CMD_PORT.print(ff_norm_1); CMD_PORT.print(", "); CMD_PORT.print(ff_norm_2); CMD_PORT.println(")");
    return;
  }
  else if (cmd.equalsIgnoreCase("pwm")){
    // PWM target: <"pwm", pwm1_norm, pwm2_norm>
    String rest = (comma == -1) ? "" : inside.substring(comma + 1); rest.trim();
    int c1 = rest.indexOf(','); if (c1 == -1) return; String s1 = rest.substring(0, c1); String s2 = rest.substring(c1+1);
    s1.trim(); s2.trim();
    
    // [Modified] Parse normalized PWM(-1..1)
    float pwm_norm_1 = s1.toFloat(); // Previously s1.toInt()
    float pwm_norm_2 = s2.toFloat(); // Previously s2.toInt()
    
    // [Modified] Denormalize PWM
    pwm_goal_1 = clamp_pwm((long)(pwm_norm_1 * PWM_MAX));
    pwm_goal_2 = clamp_pwm((long)(pwm_norm_2 * PWM_MAX));
    
    // Switch to PWM mode
    g_mode = MODE_PWM;
    // [Modified] Print normalized PWM
    CMD_PORT.print("[cmd] MODE_PWM pwm_norm=("); CMD_PORT.print(pwm_norm_1); CMD_PORT.print(", "); CMD_PORT.print(pwm_norm_2); CMD_PORT.println(")");
    return;
  }
  else if (cmd.equalsIgnoreCase("pwm")){
    // PWM target: <"pwm", pwm1, pwm2>
    String rest = (comma == -1) ? "" : inside.substring(comma + 1); rest.trim();
    int c1 = rest.indexOf(','); if (c1 == -1) return; String s1 = rest.substring(0, c1); String s2 = rest.substring(c1+1);
    s1.trim(); s2.trim();
    
    // Set target PWM
    pwm_goal_1 = clamp_pwm(s1.toInt()); pwm_goal_2 = clamp_pwm(s2.toInt());
    
    // Switch to PWM mode
    g_mode = MODE_PWM;
    CMD_PORT.print("[cmd] MODE_PWM pwm=("); CMD_PORT.print(pwm_goal_1); CMD_PORT.print(", "); CMD_PORT.print(pwm_goal_2); CMD_PORT.println(")");
    return;
  }
  else{
    CMD_PORT.print("[cmd] unknown: "); CMD_PORT.println(cmd);
  }
}

// ======================= Arduino Entry Point =======================
void setup(){
  CMD_PORT.begin(CMD_BAUD); STAT_PORT.begin(STAT_BAUD); delay(200);
  dxl.begin(DXL_BAUD); dxl.setPortProtocolVersion(2.0);
  setup_motors_to_pwm_mode(); setup_sync_read();
#if USE_BULK
  setup_bulk_write();
#endif
  CMD_PORT.println("=== Gripper Controller (syncRead + dual write) @50Hz ===");
  CMD_PORT.print("DXL baud="); CMD_PORT.println(DXL_BAUD);
}

void loop(){
  static uint32_t last_ms = 0; uint32_t now = millis();

  // Receive commands
  static String buf;
  while (CMD_PORT.available()){
    char c = (char)CMD_PORT.read();
    if (c == '\r' || c == '\n') { handle_command_line(buf); buf = ""; }
    else { buf += c; if (buf.length() > 128) buf = ""; }
  }

  // 50Hz control + feedback
  if (now - last_ms >= LOOP_DT_MS){
    last_ms = now;

    bool ok = read_positions_dual();
    if (!ok){ CMD_PORT.println("[syncRead] fail"); }
    else{
      // =================================================================
      // [Modified] Normalize state variables
      // =================================================================
      int16_t u1 = 0, u2 = 0;
      float pos_norm_1 = 0.0f, pos_norm_2 = 0.0f;
      float tgt_norm_1 = 0.0f, tgt_norm_2 = 0.0f;

      // 1. Calculate current normalized position (0.0 ~ 1.0)
      if (limits_valid) {
        long range1 = (long)close_limit[0] - (long)open_limit[0];
        long range2 = (long)close_limit[1] - (long)open_limit[1];
        if (range1 != 0) pos_norm_1 = (float)((long)g_pos1 - (long)open_limit[0]) / (float)range1;
        if (range2 != 0) pos_norm_2 = (float)((long)g_pos2 - (long)open_limit[1]) / (float)range2;
        
        // Safety clamp to prevent overshoot causing > 1.0 or < 0.0
        if (pos_norm_1 < 0.0f) pos_norm_1 = 0.0f; if (pos_norm_1 > 1.0f) pos_norm_1 = 1.0f;
        if (pos_norm_2 < 0.0f) pos_norm_2 = 0.0f; if (pos_norm_2 > 1.0f) pos_norm_2 = 1.0f;
      }

      // 2. Calculate raw PWM and normalized target position
      if (g_mode == MODE_POS && limits_valid){
        // Position mode: P control + feedforward
        int32_t tgt1 = lerp_counts(open_limit[0], close_limit[0], goal_norm_1);
        int32_t tgt2 = lerp_counts(open_limit[1], close_limit[1], goal_norm_2);
        u1 = clamp_pwm((int32_t)(KP * (tgt1 - g_pos1)) + feed_pwm_1);
        u2 = clamp_pwm((int32_t)(KP * (tgt2 - g_pos2)) + feed_pwm_2);
        
        // Target position = received normalized target
        tgt_norm_1 = goal_norm_1;
        tgt_norm_2 = goal_norm_2;

      } else if (g_mode == MODE_PWM){
        // PWM mode: Send target PWM directly
        u1 = pwm_goal_1; 
        u2 = pwm_goal_2; 
        
        // Target position = current normalized position (because no position target)
        tgt_norm_1 = pos_norm_1;
        tgt_norm_2 = pos_norm_2;

      } else {
        // Not initialized or invalid mode: stay still
        u1 = 0; u2 = 0; 
        
        // Target position = current normalized position
        tgt_norm_1 = pos_norm_1;
        tgt_norm_2 = pos_norm_2;
      }

      write_pwm_dual(u1, u2);

      // 3. Calculate normalized PWM (-1.0 ~ 1.0)
      float pwm_norm_1 = (float)u1 / (float)PWM_MAX;
      float pwm_norm_2 = (float)u2 / (float)PWM_MAX;

      // Safety clamp
      if (pwm_norm_1 < -1.0f) pwm_norm_1 = -1.0f; if (pwm_norm_1 > 1.0f) pwm_norm_1 = 1.0f;
      if (pwm_norm_2 < -1.0f) pwm_norm_2 = -1.0f; if (pwm_norm_2 > 1.0f) pwm_norm_2 = 1.0f;


      // 4. Status output (all use normalized values, keep 4 decimal places)
      STAT_PORT.print("<");
      STAT_PORT.print(DXL_ID_1); STAT_PORT.print(",");
      STAT_PORT.print(pos_norm_1, 4);   STAT_PORT.print(","); // Normalized current position
      STAT_PORT.print(tgt_norm_1, 4);     STAT_PORT.print(","); // Normalized target position
      STAT_PORT.print(pwm_norm_1, 4);       STAT_PORT.print(","); // Normalized PWM
      STAT_PORT.print(DXL_ID_2); STAT_PORT.print(",");
      STAT_PORT.print(pos_norm_2, 4);   STAT_PORT.print(","); // Normalized current position
      STAT_PORT.print(tgt_norm_2, 4);     STAT_PORT.print(","); // Normalized target position
      STAT_PORT.print(pwm_norm_2, 4);       STAT_PORT.println(">"); // Normalized PWM
    }
  }
}

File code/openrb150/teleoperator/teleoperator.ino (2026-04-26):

#include <Dynamixel2Arduino.h>

// --- Constants ---

// On OpenRB-150, the DXL serial port is Serial1
#define DXL_SERIAL Serial1
// The DIR pin is not needed for OpenRB-150
const int DXL_DIR_PIN = -1; 

// Motor IDs for this sensor board
const uint8_t DXL_ID_3 = 3;
const uint8_t DXL_ID_4 = 4;

// Communication Baud Rate
const int BAUDRATE = 57600;

// Create Dynamixel2Arduino object
Dynamixel2Arduino dxl(DXL_SERIAL, DXL_DIR_PIN);

// This namespace is required to use control table item names like PRESENT_LOAD
using namespace ControlTableItem;

void setup() {
  // Start the USB Serial for communication with the PC
  // This baud rate must match the Python script's BAUD RATE.
  Serial.begin(115200);                                                                                                                                                                                                                                                                                                                                                                                                                                                                                                                                                                                                                                                                                                                                                                                                                                                                                                                                                                                                                                                                                                                                                                                                                                                                                                                                                                                                                                                                                                                                                                                                                                                                                                                                                                                                                                                                                                                                                                                                                                                                                                                                                                                                                                                                                                                                                                                                                                                                                                                
  // while (!Serial); // Wait for Serial Monitor to connect

  // Start the Dynamixel bus
  dxl.begin(BAUDRATE);
  // Set the protocol version to 2.0
  dxl.setPortProtocolVersion(2.0);

  uint8_t dxl_ids[] = {DXL_ID_3, DXL_ID_4};
  for (int i = 0; i < 2; i++) {
    uint8_t dxl_id = dxl_ids[i];
    
    if (dxl.ping(dxl_id)) {
      // Successfully found motor
    } else {
      // Failed to find motor, stop here
      while(1);
    }

    // Set Operating Mode to Position Control (Mode 3)
    dxl.writeControlTableItem(OPERATING_MODE, dxl_id, 3);
    
    // Read the current position
    int32_t initial_position = dxl.readControlTableItem(PRESENT_POSITION, dxl_id);

    // Set the current position as the goal position to hold it
    dxl.writeControlTableItem(GOAL_POSITION, dxl_id, initial_position);
    
    // Enable Torque
    dxl.writeControlTableItem(TORQUE_ENABLE, dxl_id, 1);
  }
}

void loop() {
  // 1. Read the PRESENT_LOAD value for both motors first
  int16_t load3 = dxl.readControlTableItem(PRESENT_LOAD, DXL_ID_3);
  int16_t load4 = dxl.readControlTableItem(PRESENT_LOAD, DXL_ID_4);
  
  // 2. --- KEY CHANGE ---
  // Construct a single string in the format "L3:value,L4:value"
  // This format is required by the Python script.
  Serial.print("L3:");
  Serial.print(load3);
  Serial.print(",L4:");
  // Use println() on the last part to send the newline character,
  // which tells Python the message is complete.
  Serial.println(load4);
  
  // A small delay to control the data rate. 10ms = ~100Hz
  delay(10); 
}

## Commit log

2026-04-29 add teleoperator cad
    [teleoperator.step, teleoperator_solid.step]
2026-06-15 update driving pulley
    [driving_pulley.stl]
2026-06-15 add urdf
    [base-1.stl, left_figure.stl, right_figure.stl]
